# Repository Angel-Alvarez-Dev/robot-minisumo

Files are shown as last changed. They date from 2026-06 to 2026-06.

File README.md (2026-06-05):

# Robot Minisumo

Robot Minisumo autonomo basado en Arduino Nano y Arduino Nano Expansion I/O Shield. El prototipo fisico fue probado y se encuentra funcional con sensores TCRT5000, HC-SR04, buzzer KY-012 y servomotores SG90.

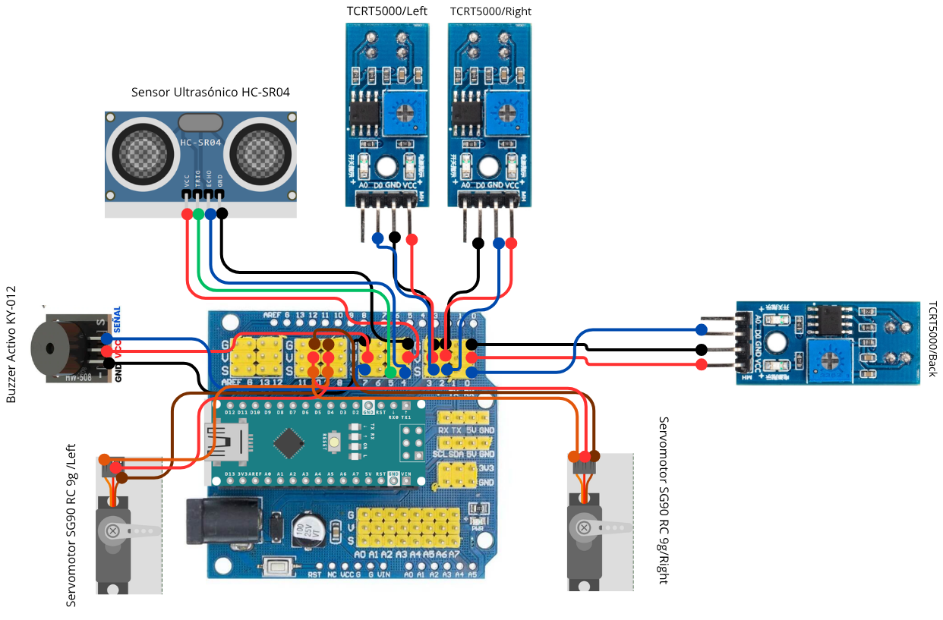
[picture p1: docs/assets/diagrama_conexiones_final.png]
Diagrama final de conexiones


PDF del diagrama final: [docs/assets/diagrama_conexiones_final.pdf](docs/assets/diagrama_conexiones_final.pdf)

## Estado del proyecto

El prototipo fisico del Robot Minisumo fue probado y se encuentra funcional. El Arduino Nano tiene cargada y confirmada por Serial la version funcional `1.0.0-funcional` del firmware final. El repositorio contiene firmware, documentacion, esquematicos KiCad, validacion logica y reporte academico en carpeta separada.

## Componentes

| Componente | Cantidad | Funcion |
| --- | --- | --- |
| Porta Pilas AA Con Plug Para 4/6 Pilas | 1 (EL DE 4) | Fuente portatil para alimentar el robot mediante la Shield. |
| Paquete De 4 Pilas Alcalinas AA | 1.0 | Energia para el porta pilas AA. |
| Sensor Seguidor de Linea TCRT5000 Optico Infrarrojo 3.3 V a 5 V | 3.0 | Deteccion de borde de dohyo con tres sensores Left, Right y Back. |
| Sensor Ultrasónico HC-SR04 | 2.0 | Componente de soporte del robot. |
| Buzzer Activo KY-012 | 2.0 | Indicador sonoro de arranque, ataque y evasion. |
| Arduino Nano V3 + cable USB | 1.0 | Control principal de lectura de sensores y actuadores. |
| Shield para Arduino Nano Expansion I/O | 1.0 | Control principal de lectura de sensores y actuadores. |
| Servomotor SG90 RC 9g | 2.0 | Traccion diferencial del robot con SG90 confirmados funcionales. |
| Llantas de plástico | 2.0 | Contacto mecanico de traccion para los servos. |
| Cables Dupont Largos 20cm HH MH MM | 1-HH/1MH/1MM (uNO DE CADA UNO) | Cableado de senales, VCC y GND entre modulos y Shield. |

## Pinout final

| Componente | Pin del componente | Pin Arduino/Shield | Senal |
| --- | --- | --- | --- |
| TCRT5000 Left | DO | D3 | TCRT_LEFT |
| TCRT5000 Right | DO | D2 | TCRT_RIGHT |
| TCRT5000 Back | DO | D0 | TCRT_BACK |
| HC-SR04 | Trig | D4 | TRIG_HCSR04 |
| HC-SR04 | Echo | D5 | ECHO_HCSR04 |
| KY-012 | S | D7 | BUZZER_SIG |
| SG90 Left | Signal | D9 | SERVO_LEFT |
| SG90 Right | Signal | D10 | SERVO_RIGHT |

## Advertencias tecnicas

- D0 corresponde a RX Serial del Arduino Nano. En el prototipo final se usa para `TCRT_BACK`; si interfiere con la carga de firmware o monitor serial, desconectar temporalmente el DO del sensor trasero.
- Todos los modulos deben compartir GND comun.
- La Shield de expansion organiza conexiones, pero no aumenta la capacidad de corriente del Arduino Nano.
- Si los servos reinician el Arduino o vibran, usar alimentacion externa estable de 5 V para servos con GND comun.

## Compilar firmware

```powershell
$Cli = 'A:\robot-minisumo\tools\arduino-cli\arduino-cli.exe'
$Config = 'A:\robot-minisumo\.arduino-cli\arduino-cli.yaml'
& $Cli --config-file $Config compile --fqbn arduino:avr:nano firmware\robot_minisumo_final
```

## Firmware cargado

Firmware final: `firmware/robot_minisumo_final/robot_minisumo_final.ino`.

Version confirmada desde Serial Monitor:

```text
Robot Minisumo Final
1.0.0-funcional
FUNCIONAL_PROBADO
```

La carga fue confirmada en `COM8` usando `arduino:avr:nano`.

## KiCad

Abrir `hardware/kicad/robot_minisumo.kicad_pro`. El esquematico representa el montaje sobre Arduino Nano Expansion I/O Shield; no se disena PCB personalizada.

## Documentacion

- BOM final: `docs/bom_final.md`.
- Conexiones finales: `docs/lista_conexiones_final.md`.
- Panel de monitoreo: `docs/panel_web_monitoreo.md`.
- Algoritmos y pseudocodigo: `docs/algoritmos.md`, `docs/pseudocodigo.md`.
- Validacion: `validation/` y `simulation/`.
- Reporte academico: `report/`.

## Panel web de monitoreo

Abrir `web-control/index.html` o servir el repositorio en `http://localhost:8080/web-control/`.

El panel esta disenado para grabar y explicar el robot en funcionamiento en una sola pantalla de laptop. Muestra conexion, firmware, distancia, accion actual, modo real/demo, procesos activos, TCRT5000 Left/Right/Back, HC-SR04, servos SG90, buzzer KY-012, movimiento y eventos recientes.

Incluye:

- Modo demo / grabacion con estados simulados desde el panel.
- Pruebas rapidas: sensores, servos, buzzer, ultrasonico, demo borde, demo ataque, demo buscar y stop.
- Conexion opcional por Web Serial API a 9600 baudios.
- Envio de comandos `CMD:TEST_SENSORES`, `CMD:TEST_SERVOS`, `CMD:TEST_BUZZER`, `CMD:TEST_ULTRASONICO`, `CMD:DEMO_BORDE`, `CMD:DEMO_ATAQUE`, `CMD:DEMO_BUSCAR` y `CMD:STOP`.
- Parseo de mensajes `STATE`, `TCRT_LEFT`, `TCRT_RIGHT`, `TCRT_BACK`, `DIST_CM`, `OPONENTE`, `MOTOR_LEFT`, `MOTOR_RIGHT` y `BUZZER`.
- Compatibilidad con la linea de prueba `Distancia=<cm> L=<0/1> R=<0/1> B=<0/1>`.

## Evidencia del proyecto

La evidencia multimedia final esta organizada en `assets/` y documentada en `docs/evidencia_multimedia.md` e `docs/inventario_multimedia.md`.

| Carpeta | Contenido |
| --- | --- |
| `assets/images/conexiones/` | Diagrama final de conexiones del robot. |
| `assets/images/montaje/` | Fotografias del prototipo fisico ensamblado. |
| `assets/images/pruebas/` | Evidencia visual de alimentacion y sensores activos. |
| `assets/images/panel/` | Capturas del panel web de monitoreo. |
| `assets/videos/pruebas/` | Videos cortos de pruebas por componente o comportamiento. |
| `assets/videos/demo_final/` | Video principal de funcionamiento final. |

Archivo principal para demostracion: `assets/videos/demo_final/robot_minisumo_demo_funcionamiento_final_01.mp4`.

La publicacion en GitHub fue revisada en `docs/github_publicacion.md`; los videos integrados son ligeros y no requieren Git LFS.
## Licencia

Proyecto academico y tecnico. Agregar licencia explicita si se publicara para reutilizacion externa.

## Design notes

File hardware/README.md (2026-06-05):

# Hardware

El hardware final usa Arduino Nano sobre Arduino Nano Expansion I/O Shield. El montaje se documenta por bloques y no requiere PCB personalizada.

| Archivo | Proposito |
| --- | --- |
| `conexiones_robot_minisumo.md` | Conexion detallada por bloque |
| `esquematicos.md` | Descripcion del esquematico |
| `kicad/robot_minisumo.kicad_sch` | Proyecto KiCad documental |
| `assets/diagrama_conexiones.png` | Diagrama visual |

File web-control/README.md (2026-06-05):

# Panel compacto Robot Minisumo

Panel web local para grabar el video final del Robot Minisumo sin scroll innecesario. La vista concentra proceso activo, sensores, actuadores, movimiento, pruebas rapidas y eventos recientes.

## Abrir

```powershell
cd A:\robot-minisumo
python -m http.server 8080
```

Abrir:

```text
http://localhost:8080/web-control/
```

Tambien puede abrirse directo con `web-control/index.html`, pero `localhost` es mejor para Web Serial.

## Vista en tiempo real

- Conexion: conectado, desconectado o modo demo.
- Firmware: detectado o no detectado.
- Distancia: valor HC-SR04 en cm o sin eco.
- Accion: buscar, atacar, evadir borde, giro, retroceso o detenido.
- Modo: real o demo.
- TCRT Left, Right y Back: libre, borde o inestable.
- Servo Left y Servo Right: stop, avanza, atras, gira o ataque.
- Buzzer: ON/OFF.
- Movimiento resumido del robot.

## Pruebas rapidas

| Boton | Comando Serial | Efecto visual |
| --- | --- | --- |
| Test sensores | `CMD:TEST_SENSORES` | Lectura linea y tarjetas TCRT |
| Test servos | `CMD:TEST_SERVOS` | Movimiento de servos |
| Test buzzer | `CMD:TEST_BUZZER` | Buzzer ON temporal |
| Test ultrasonico | `CMD:TEST_ULTRASONICO` | Distancia y oponente |
| Demo borde | `CMD:DEMO_BORDE` | Borde, retroceso y buzzer |
| Demo ataque | `CMD:DEMO_ATAQUE` | Ataque y oponente cerca |
| Demo buscar | `CMD:DEMO_BUSCAR` | Busqueda/giro |
| Stop | `CMD:STOP` | Detiene motores |

Si Arduino esta conectado por Web Serial, el panel envia el comando. Si no esta conectado, el panel activa modo demo y simula el estado para grabacion.

## Web Serial

El boton `Conectar Arduino` abre Web Serial API a 9600 baudios. El firmware final reconoce los comandos `CMD:*` anteriores y publica telemetria.

Mensajes leidos por el panel:

- `STATE:BUSCAR`
- `STATE:ATACAR`
- `STATE:EVITAR_BORDE`
- `STATE:RETROCESO` o `STATE:RETROCEDER`
- `STATE:GIRO_IZQUIERDO`
- `STATE:GIRO_DERECHO`
- `STATE:DETENIDO` o `STATE:DETENER`
- `TCRT_LEFT:0`
- `TCRT_RIGHT:1`
- `TCRT_BACK:0`
- `DIST_CM:23`
- `OPONENTE:1`
- `MOTOR_LEFT:AVANZAR`
- `MOTOR_RIGHT:RETROCEDER`
- `BUZZER:ON`
- `BUZZER:OFF`

Los mensajes desconocidos no rompen la interfaz; solo aparecen en eventos recientes.

## Limitaciones

- Web Serial requiere navegador compatible, normalmente Chromium.
- Para ver telemetria real hay que cargar el firmware actualizado en Arduino.
- D0/RX se usa para `TCRT_BACK`; desconectar temporalmente ese sensor si interfiere con carga de firmware.

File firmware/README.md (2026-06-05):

# Firmware

## Version funcional cargada

El Arduino Nano tiene cargada y confirmada por Serial la version funcional del firmware final:

```text
Robot Minisumo Final
1.0.0-funcional
FUNCIONAL_PROBADO
```

Archivo final: `firmware/robot_minisumo_final/robot_minisumo_final.ino`.

Puerto confirmado: `COM8`.

FQBN usado para carga: `arduino:avr:nano`.

## Pinout final

| Senal | Pin |
| --- | --- |
| TCRT_LEFT | D3 |
| TCRT_RIGHT | D2 |
| TCRT_BACK | D0 |
| TRIG_HCSR04 | D4 |
| ECHO_HCSR04 | D5 |
| BUZZER_SIG | D7 |
| SERVO_LEFT | D9 |
| SERVO_RIGHT | D10 |

D0 se usa para `TCRT_BACK` segun el pinout real probado. D0 corresponde a RX Serial; si falla la carga o el monitor serial, desconectar temporalmente el cable DO del TCRT Back.

## Calibracion final

- `LINE_ACTIVE_LOW = true`.
- Distancia de ataque: 35 cm.
- SG90 Left en D9: 1700 us avanza y 1300 us retrocede.
- SG90 Right en D10: 1300 us acompana el avance y 1700 us retrocede por montaje invertido.
- Detencion: 1500 us.

## Sketches

- `test_hcsr04`: prueba Trig D4 / Echo D5.
- `test_tcrt5000`: prueba RAW Left D3, Right D2, Back D0.
- `test_servos`: prueba D9/D10 con pulsos manuales.
- `test_buzzer`: prueba KY-012 en D7.
- `test_servo_d9`: prueba aislada de calibracion D9.
- `robot_minisumo_final`: firmware autonomo final.

## Comandos Serial del firmware final

- `s`: imprimir sensores en formato `Distancia=<cm> L=<0/1> R=<0/1> B=<0/1>`.
- `v`: prueba breve de servos.
- `b`: sonar buzzer.
- `a`: avanzar 500 ms.
- `d`: detener.

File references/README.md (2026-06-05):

# Referencias tecnicas

Carpeta minima de referencias de componentes.

Se conservan solo archivos necesarios para documentar y validar el proyecto:

- Datasheets relevantes.
- Pinouts.
- Imagenes de dimensiones.
- Esquematico de la shield.

No se conservan en la estructura limpia los paquetes CAD completos, renders duplicados ni archivos temporales de modelado.

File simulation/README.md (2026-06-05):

# Simulacion

La validacion es logica y documental hasta realizar pruebas fisicas. El esquematico KiCad representa bloques de conexion sobre la Shield.

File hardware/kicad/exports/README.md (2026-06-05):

# Exportaciones KiCad

Pendiente ejecutar con KiCad instalado:

```powershell
kicad-cli sch erc hardware\kicad\robot_minisumo.kicad_sch --output hardware\kicad\exports\erc_report.txt
kicad-cli sch export pdf hardware\kicad\robot_minisumo.kicad_sch --output hardware\kicad\exports\robot_minisumo_schematic.pdf
kicad-cli sch export svg hardware\kicad\robot_minisumo.kicad_sch --output hardware\kicad\exports\
```

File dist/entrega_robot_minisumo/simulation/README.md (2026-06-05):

# Simulacion Y Validacion

Estado del prototipo fisico: **funcional**.

La validacion combina pruebas fisicas por modulo, compilacion de firmware y analisis de logica. El proyecto no depende de una simulacion electrica analogica compleja; el comportamiento se valida por casos de entrada/salida y esquematico KiCad documental.

| Caso | Entrada | Accion esperada | Resultado esperado | Estado |
| --- | --- | --- | --- | --- |
| HC-SR04 detecta oponente | Distancia 5 a 35 cm | Atacar | Servos avanzan y buzzer breve | Validado logicamente |
| HC-SR04 no detecta oponente | Distancia > 35 cm o sin eco | Buscar | Robot gira buscando | Validado logicamente |
| TCRT5000 Left detecta borde | Left activo | Evadir | Retrocede y gira derecha | Validado logicamente |
| TCRT5000 Right detecta borde | Right activo | Evadir | Retrocede y gira izquierda | Validado logicamente |
| TCRT5000 Back detecta borde | Back activo en D0 | Evadir | Retrocede y giro extendido | Validado logicamente |
| Servo izquierdo responde | Pulso D9 | Mover | 1700 us avanza; 1300 us retrocede | Aprobado fisico |
| Servo derecho responde | Pulso D10 | Mover | Acompana invertido por montaje | Aprobado fisico |
| Buzzer responde | D7 alto | Sonar | Sonido confirmado | Aprobado fisico |
| Robot busca | Sin borde y sin oponente | Girar | Busqueda continua | Validado |
| Robot ataca | Oponente cercano | Avanzar | Ataque con servos | Validado |
| Robot evita borde | TCRT activo | Retroceder/girar | No sale del area | Validado |
| Robot funciona fisicamente | Pinout final conectado | Operar | Prototipo funcional | Aprobado fisico |

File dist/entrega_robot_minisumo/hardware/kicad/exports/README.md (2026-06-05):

# Exportaciones KiCad

Ejecutar si `kicad-cli` esta disponible:

```powershell
kicad-cli version
kicad-cli sch erc hardware/kicad/robot_minisumo.kicad_sch --output hardware/kicad/exports/erc_report.txt
kicad-cli sch export pdf hardware/kicad/robot_minisumo.kicad_sch --output hardware/kicad/exports/robot_minisumo_schematic.pdf
kicad-cli sch export svg hardware/kicad/robot_minisumo.kicad_sch --output hardware/kicad/exports/
```

Si `kicad-cli` no esta instalado, abrir `hardware/kicad/robot_minisumo.kicad_pro` en KiCad y ejecutar manualmente Inspeccion electrica y Exportar PDF/SVG.

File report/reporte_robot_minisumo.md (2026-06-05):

# Reporte Academico: Robot Minisumo

## 1. Portada

**Alumno:** Álvarez Villegas José Ángel  
**Materia:** MICROCONTROLADORES  
**Grupo:** 2809  
**Proyecto:** Robot Minisumo  
**Fecha:** 2026-06-05

## 2. Indice

1. Introduccion.
2. Objetivo general.
3. Objetivos especificos.
4. Investigacion documental.
5. Materiales y equipo.
6. Lista final de conexiones.
7. Diagrama final de conexiones.
8. Esquematicos del circuito.
9. Funcionamiento del sistema.
10. Codigo implementado.
11. Panel de monitoreo para demostracion.
12. Algoritmos.
13. Pseudocodigo.
14. Diagramas de flujo.
15. Simulacion y validacion.
16. Pruebas realizadas.
17. Evidencia del prototipo funcional.
18. Resultados.
19. Conclusiones.
20. Referencias.
21. Anexos.

## 3. Introduccion

El Robot Minisumo es un sistema autonomo basado en Arduino Nano que usa sensores de linea para detectar el borde del area de competencia, un sensor ultrasonico HC-SR04 para localizar al oponente, servomotores SG90 para traccion diferencial y un buzzer KY-012 para senalizacion.

## 4. Objetivo general

Consolidar un prototipo funcional de Robot Minisumo con firmware, documentacion, esquematico KiCad, validacion y carpeta de entrega coherentes con las conexiones finales reales.

## 5. Objetivos especificos

- Documentar la BOM final.
- Documentar la lista final de conexiones.
- Implementar firmware modular para busqueda, ataque y evasion de borde.
- Validar sensores, servos y buzzer con pruebas individuales.
- Generar reporte academico y entregables finales.

## 6. Investigacion documental

El Arduino Nano se usa como controlador principal por su compatibilidad con el ecosistema Arduino y disponibilidad de entradas/salidas digitales. El HC-SR04 mide distancia por tiempo de vuelo ultrasonico. Los TCRT5000 integran emisor infrarrojo y fototransistor para detectar cambios de reflectancia. Los SG90 de rotacion continua permiten traccion simple mediante pulsos tipo servo, y el KY-012 entrega senal sonora con control digital.

## 7. Materiales y equipo

Ver `docs/bom_final.md` y `report/assets/bom_final.md`.

## 8. Lista final de conexiones

| Componente | Pin del componente | Pin Arduino/Shield | Senal |
| --- | --- | --- | --- |
| TCRT5000 Left | DO | D3 | TCRT_LEFT |
| TCRT5000 Right | DO | D2 | TCRT_RIGHT |
| TCRT5000 Back | DO | D0 | TCRT_BACK |
| HC-SR04 | Trig | D4 | TRIG_HCSR04 |
| HC-SR04 | Echo | D5 | ECHO_HCSR04 |
| KY-012 | S | D7 | BUZZER_SIG |
| SG90 Left | Signal | D9 | SERVO_LEFT |
| SG90 Right | Signal | D10 | SERVO_RIGHT |

Advertencia: D0 y D1 corresponden a RX/TX del Arduino Nano. El prototipo final usa D0 para `TCRT_BACK`, por lo que se debe desconectar temporalmente durante carga si interfiere.

## 9. Diagrama final de conexiones

Diagrama final de conexiones

Version PDF del diagrama final: `assets/diagrama_conexiones_final.pdf`.

## 10. Esquematicos del circuito

El proyecto KiCad esta en `hardware/kicad/robot_minisumo.kicad_pro`. El esquematico es documental y representa el montaje real sobre Shield, con GND comun, VCC_5V para sensores/buzzer y alimentacion estable para servos.

## 11. Funcionamiento del sistema

El robot da prioridad a la deteccion de borde. Si cualquier TCRT5000 detecta borde, retrocede y gira. Si no hay borde, mide distancia con HC-SR04. Si detecta un oponente a 35 cm o menos, avanza para atacar. Si no detecta oponente, busca girando.

## 12. Codigo implementado

```cpp
const byte PIN_TCRT_LEFT = 3;
const byte PIN_TCRT_RIGHT = 2;
const byte PIN_TCRT_BACK = 0;
const byte PIN_TRIG_HCSR04 = 4;
const byte PIN_ECHO_HCSR04 = 5;
const byte PIN_BUZZER = 7;
const byte PIN_SERVO_LEFT = 9;
const byte PIN_SERVO_RIGHT = 10;
```

Funciones principales: `configurarPines`, `leerUltrasonico`, `leerSensoresLinea`, `avanzar`, `retroceder`, `girarIzquierda`, `girarDerecha`, `detenerRobot`, `buscarOponente`, `atacar`, `evitarBorde`, `sonarBuzzer`, `pruebaSensores`, `pruebaUltrasonico`, `pruebaServos`, `procesarComandoPanel` y `publicarEstadoPanel`.

## 13. Panel de monitoreo para demostracion

Se agrego un panel web de monitoreo compacto en `web-control/` para apoyar la grabacion del robot funcionando. El objetivo del panel es mostrar en una sola pantalla de laptop lo importante de la operacion: proceso activo, sensores, actuadores, movimiento, pruebas rapidas y eventos recientes.

Componentes monitoreados:

- HC-SR04 ultrasonico.
- TCRT5000 Left, Right y Back.
- Servo/Motor izquierdo SG90.
- Servo/Motor derecho SG90.
- Buzzer KY-012.
- Movimiento resumido del robot.

Procesos mostrados:

- Inicializacion.
- Lectura de linea.
- Lectura ultrasonica.
- Buscar.
- Ataque.
- Evadir borde.
- Retroceso.
- Giro izquierdo.
- Giro derecho.
- Detenido.

El panel incluye modo demo / grabacion. En este modo los estados son simulados desde el panel y se indica claramente al usuario que no corresponden a lecturas reales del Arduino. Esto permite preparar tomas de video donde se expliquen casos como borde, ataque, busqueda, pruebas de sensores, pruebas de servos, buzzer y detencion.

Tambien se implemento integracion opcional con Web Serial API. Si el navegador soporta Web Serial, el boton `Conectar Arduino` permite seleccionar el puerto del Arduino a 9600 baudios. El firmware final publica mensajes como `STATE:BUSCAR`, `STATE:ATACAR`, `TCRT_LEFT:1`, `DIST_CM:20`, `MOTOR_LEFT:AVANZAR` y `BUZZER:ON`. El panel parsea esos mensajes y actualiza sensores, actuadores, procesos y registro compacto de eventos.

El panel tambien incluye botones de pruebas rapidas. Si existe conexion Web Serial, envia comandos como `CMD:TEST_SENSORES`, `CMD:TEST_SERVOS`, `CMD:TEST_BUZZER`, `CMD:TEST_ULTRASONICO`, `CMD:DEMO_BORDE`, `CMD:DEMO_ATAQUE`, `CMD:DEMO_BUSCAR` y `CMD:STOP`. Si no existe conexion, los botones activan modo demo y actualizan visualmente el tablero.

Descripcion visual del panel: en la parte superior se muestran conexion, firmware, distancia, accion y modo. La zona central contiene chips de procesos y tarjetas compactas para TCRT Left/Right/Back, HC-SR04, Servo Left, Servo Right, Buzzer y movimiento. Debajo se ubican los botones de pruebas rapidas y un log limitado a eventos recientes.

La utilidad principal durante la grabacion es que toda la informacion importante cabe en la vista de la laptop, sin depender de scroll, y permite explicar que sensor se activo, que actuador responde y que movimiento hace el robot.

## 14. Algoritmos

Ver `docs/algoritmos.md`.

## 15. Pseudocodigo

Ver `docs/pseudocodigo.md`.

## 16. Diagramas de flujo

Ver `docs/diagramas_flujo.md`.

## 17. Simulacion y validacion

Ver `simulation/casos_prueba.md`, `simulation/validacion_logica.md` y `validation/registro_pruebas.md`.

## 18. Pruebas realizadas

| Prueba | Resultado esperado | Resultado observado | Estado |
| --- | --- | --- | --- |
| Buzzer KY-012 | Sonido intermitente al ejecutar test_buzzer | Sonido confirmado por usuario | Aprobado |
| HC-SR04 | Lecturas de distancia en cm | Lecturas observadas: 151, 152, 46, 47, 4, 11, 16, 7 y 6 cm | Aprobado |
| TCRT5000 Left | Cambio digital al detectar linea/borde | Los tres sensores funcionan con tabla final: Left D3, Right D2, Back D0 | Aprobado |
| TCRT5000 Right | Cambio digital al detectar linea/borde | Los tres sensores funcionan con tabla final: Left D3, Right D2, Back D0 | Aprobado |
| TCRT5000 Back | Cambio digital al detectar linea/borde | Funciona en D0; advertencia por RX Serial documentada | Aprobado |
| Servo D9 aislado | Movimiento adelante y atras | 1700 us adelanta y 1300 us atrasa | Aprobado |
| Servos D9/D10 conjunto | D9 avanza y D10 acompana sin quedarse quieto | D9 avanza, D10 acompana invertido por montaje, ninguno se queda quieto | Aprobado |
| Firmware final | Arranque serial y logica cargada | Firmware final cargado en COM8 y arranque serial observado | Aprobado |
| Panel web compacto | Mostrar estado general, procesos, componentes, pruebas y eventos en una pantalla | Panel compacto actualizado con modo demo, pruebas rapidas y Web Serial opcional | Aprobado |
| Robot fisico | Prototipo opera con sensores y actuadores finales | Estado reportado por usuario: robot fisico funcional | Aprobado |

## 19. Evidencia del prototipo funcional

La evidencia multimedia del prototipo funcional se integro en `assets/` y se documento en `docs/evidencia_multimedia.md`, `docs/inventario_multimedia.md` y `validation/evidencia_funcionamiento.md`.

Evidencia visual incluida:

| Evidencia | Archivo | Utilidad |
| --- | --- | --- |
| Diagrama final de conexiones | `assets/robot_minisumo_conexiones_diagrama_final_01.png` | Explica el pinout real usado en el robot. |
| Fotografia frontal | `assets/robot_minisumo_montaje_frontal_hcsr04_01.jpg` | Muestra el HC-SR04 al frente del robot. |
| Fotografia posterior/electronica | `assets/robot_minisumo_montaje_posterior_electronica_01.jpg` | Muestra Arduino Nano, shield, buzzer y cableado. |
| Fotografia de pruebas | `assets/robot_minisumo_pruebas_alimentacion_sensores_01.jpg` | Muestra alimentacion y sensores activos. |
| Captura del panel web | `assets/robot_minisumo_panel_monitoreo_desktop_01.png` | Muestra el panel minimalista usado durante la grabacion. |

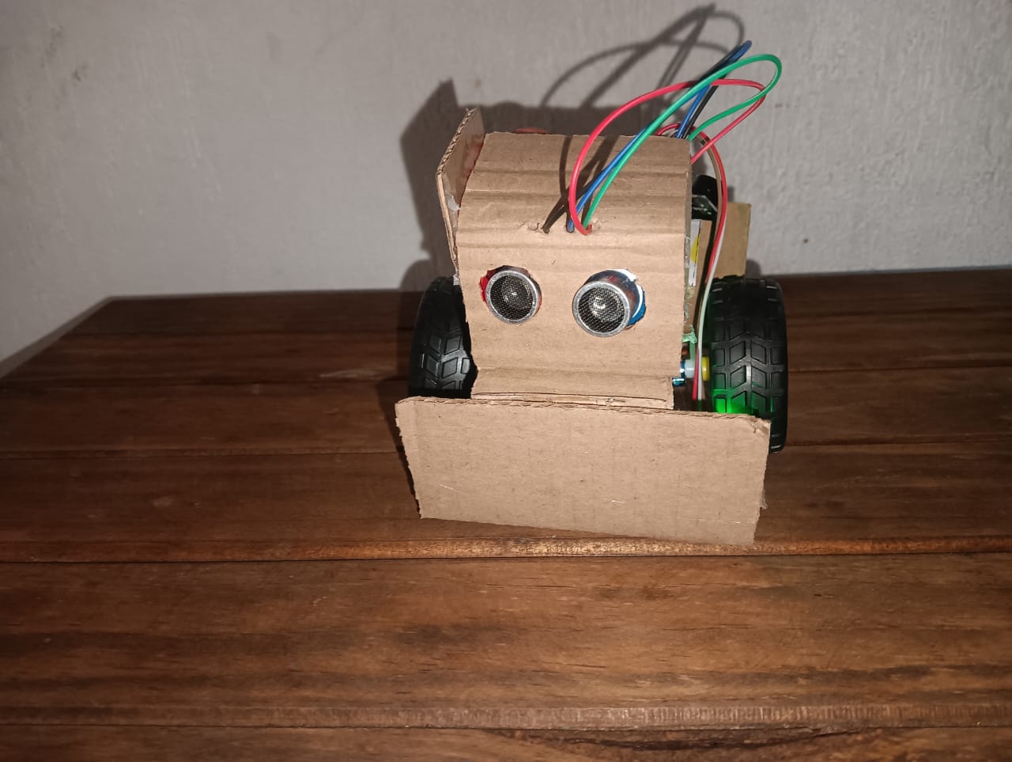
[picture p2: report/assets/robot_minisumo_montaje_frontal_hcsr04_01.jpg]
Montaje frontal del prototipo


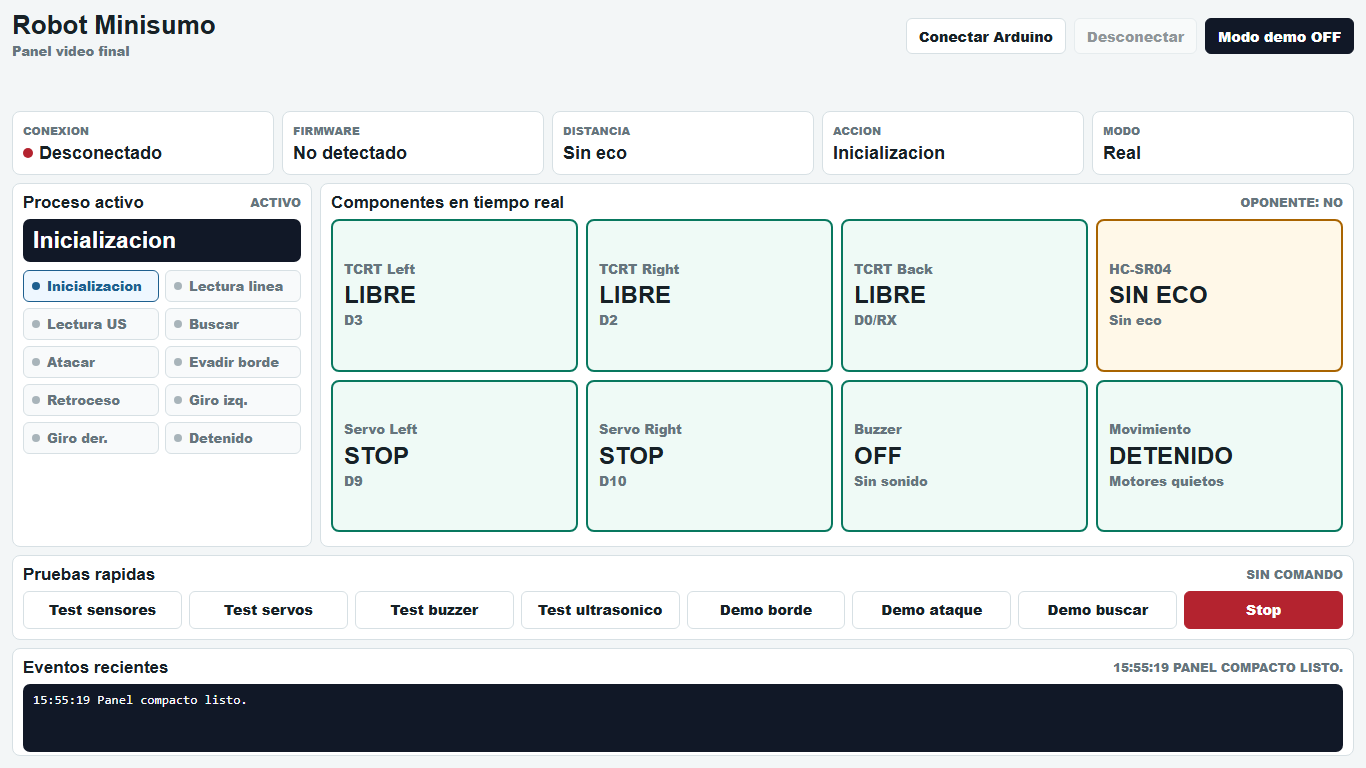
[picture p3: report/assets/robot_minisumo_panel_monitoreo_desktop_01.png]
Panel web de monitoreo


Evidencia en video incluida:

| Video | Duracion | Uso |
| --- | --- | --- |
| `assets/videos/pruebas/robot_minisumo_pruebas_buzzer_arranque_01.mp4` | 00:00:02 | Buzzer / arranque. |
| `assets/videos/pruebas/robot_minisumo_pruebas_movimiento_servos_01.mp4` | 00:00:09 | Movimiento de servos. |
| `assets/videos/pruebas/robot_minisumo_pruebas_sensores_linea_01.mp4` | 00:00:06 | Sensores TCRT5000. |
| `assets/videos/pruebas/robot_minisumo_pruebas_ultrasonico_busqueda_01.mp4` | 00:00:09 | Busqueda / HC-SR04. |
| `assets/videos/demo_final/robot_minisumo_demo_funcionamiento_final_01.mp4` | 00:00:15 | Demostracion final del robot funcional. |

Esta evidencia permite explicar durante el video final que componentes estan montados, que pruebas se realizaron y como el panel acompana la demostracion en tiempo real.

## 20. Resultados

El prototipo fisico quedo funcional. Se confirmaron buzzer, HC-SR04, tres TCRT5000 y servos SG90. El pinout final real quedo documentado y el firmware final se cargo en COM8.

La version funcional cargada fue confirmada por Serial Monitor:

```text
Robot Minisumo Final
1.0.0-funcional
FUNCIONAL_PROBADO
```

## 21. Conclusiones

El proyecto final integra hardware, firmware y documentacion de forma coherente con el robot funcional real. La principal restriccion tecnica es el uso de D0 para el sensor trasero, debido a que comparte RX Serial. La recomendacion es desconectar temporalmente ese sensor durante cargas de firmware o futuras depuraciones seriales.

## 22. Referencias

- Documentacion Arduino Nano.
- Hojas tecnicas HC-SR04, TCRT5000, SG90 y KY-012.
- Documentacion KiCad.
- BOM y lista final de conexiones anexadas al proyecto.

## 23. Anexos

- `firmware/`.
- `hardware/kicad/`.
- `docs/`.
- `simulation/`.
- `validation/`.
- `web-control/`.

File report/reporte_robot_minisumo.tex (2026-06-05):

\documentclass[12pt,letterpaper]{article}
\usepackage[utf8]{inputenc}
\usepackage[T1]{fontenc}
\usepackage[spanish]{babel}
\usepackage{geometry}
\usepackage{graphicx}
\usepackage{longtable}
\usepackage{hyperref}
\geometry{margin=2.2cm}
\title{Robot Minisumo}
\author{Álvarez Villegas José Ángel\\MICROCONTROLADORES\\Grupo 2809}
\date{2026-06-05}
\begin{document}
\maketitle
\tableofcontents
\newpage
\section{Introducción}
El Robot Minisumo es un prototipo autónomo basado en Arduino Nano, sensores TCRT5000, HC-SR04, buzzer KY-012 y servomotores SG90.
\section{Objetivo general}
Consolidar un prototipo funcional con documentación, firmware, validación, esquemático KiCad y entregables finales.
\section{Materiales y equipo}
La BOM final se documenta en \texttt{docs/bom\_final.md} y \texttt{report/assets/bom\_final.md}.
\section{Lista final de conexiones}
\begin{longtable}{p{4cm}p{3cm}p{3cm}p{4cm}}
\textbf{Componente} & \textbf{Pin componente} & \textbf{Pin Arduino} & \textbf{Señal}\\
TCRT5000 Left & DO & D3 & TCRT\_LEFT \\
TCRT5000 Right & DO & D2 & TCRT\_RIGHT \\
TCRT5000 Back & DO & D0 & TCRT\_BACK \\
HC-SR04 & Trig & D4 & TRIG\_HCSR04 \\
HC-SR04 & Echo & D5 & ECHO\_HCSR04 \\
KY-012 & S & D7 & BUZZER\_SIG \\
SG90 Left & Signal & D9 & SERVO\_LEFT \\
SG90 Right & Signal & D10 & SERVO\_RIGHT \\
\end{longtable}
\textbf{Advertencia:} D0 y D1 corresponden a RX/TX del Arduino Nano. El prototipo final usa D0 para TCRT Back, por lo que puede ser necesario desconectarlo durante carga de firmware.
\section{Diagrama final de conexiones}

Version PDF del diagrama final: \texttt{assets/diagrama\_conexiones\_final.pdf}.
\section{Funcionamiento}
El robot prioriza la evasión de borde; si no hay borde, mide distancia y ataca cuando el oponente está a 35 cm o menos. Si no detecta oponente, busca girando.
\section{Código implementado}
El firmware final se encuentra en \texttt{firmware/robot\_minisumo\_final/robot\_minisumo\_final.ino} e incluye funciones modulares de lectura, movimiento, ataque, búsqueda, evasión y pruebas.
\section{Pseudocódigo y diagramas}
Ver \texttt{docs/pseudocodigo.md} y \texttt{docs/diagramas\_flujo.md}.
\section{Simulación y validación}
La validación se documenta por casos en \texttt{simulation/casos\_prueba.md}.
\section{Pruebas realizadas}
\begin{longtable}{p{9cm}p{5cm}}
\textbf{Prueba} & \textbf{Estado}\\
Buzzer KY-012 & Aprobado \\
HC-SR04 & Aprobado \\
TCRT5000 Left & Aprobado \\
TCRT5000 Right & Aprobado \\
TCRT5000 Back & Aprobado \\
Servo D9 aislado & Aprobado \\
Servos D9/D10 conjunto & Aprobado \\
Firmware final & Aprobado \\
Robot fisico & Aprobado \\
\end{longtable}
\section{Evidencia del prototipo funcional}
La evidencia multimedia del prototipo funcional se organizo en \texttt{assets/} y se documento en \texttt{docs/evidencia\_multimedia.md}, \texttt{docs/inventario\_multimedia.md} y \texttt{validation/evidencia\_funcionamiento.md}.

\begin{longtable}{p{5cm}p{5cm}p{4cm}}
\textbf{Evidencia} & \textbf{Archivo} & \textbf{Utilidad}\\
Diagrama final & \texttt{assets/images/conexiones/robot\_minisumo\_conexiones\_diagrama\_final\_01.png} & Pinout real del robot. \\
Montaje frontal & \texttt{assets/robot\_minisumo\_montaje\_frontal\_hcsr04\_01.jpg} & HC-SR04 al frente del prototipo. \\
Montaje posterior & \texttt{assets/robot\_minisumo\_montaje\_posterior\_electronica\_01.jpg} & Arduino Nano, shield, buzzer y cableado. \\
Panel web & \texttt{assets/robot\_minisumo\_panel\_monitoreo\_desktop\_01.png} & Panel minimalista usado durante la grabacion. \\
Video final & \texttt{assets/videos/demo\_final/robot\_minisumo\_demo\_funcionamiento\_final\_01.mp4} & Demostracion del robot funcionando. \\
\end{longtable}





Los videos incluidos son ligeros para publicacion en GitHub; el archivo mas grande pesa 3.39 MB, por lo que no se uso Git LFS.

\\section{Resultados}
El prototipo físico se encuentra funcional. Se confirmaron sensores, buzzer y servos SG90 con el pinout final real.
\section{Conclusiones}
El proyecto queda listo para entrega académica y publicación técnica. El principal cuidado operativo es el uso de D0/RX para TCRT Back.
\section{Referencias}
Arduino Nano, HC-SR04, TCRT5000, SG90, KY-012, KiCad y documentación generada del proyecto.
\end{document}

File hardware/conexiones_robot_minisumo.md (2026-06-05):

# Lista Final De Conexiones

Fuente valida: `Conexiones_Robot_Minisumo.xlsx` anexo e imagen final `diagrama_conexiones_final.png`.

Version PDF del diagrama: `hardware/assets/diagrama_conexiones_final.pdf`.

Pinout final probado:

- TCRT5000 Left: D3.
- TCRT5000 Right: D2.
- TCRT5000 Back: D0.
- HC-SR04: Trig D4, Echo D5.
- Buzzer KY-012: D7.
- SG90 Left: D9.
- SG90 Right: D10.

> Advertencia: D0 y D1 corresponden a RX/TX del Arduino Nano. D0 se usa por `TCRT_BACK` en el prototipo real y puede interferir con la carga de firmware o el Serial Monitor. Si ocurre, desconectar temporalmente el cable DO del TCRT Back durante la carga.

| Componente | Pin del componente | Pin Arduino/Shield | Senal | Tipo | Observaciones |
| --- | --- | --- | --- | --- | --- |
| TCRT5000 Left | VCC | VCC | VCC_5V | Alimentacion | Modulo de linea izquierdo. |
| TCRT5000 Left | GND | GND | GND | Alimentacion | GND comun. |
| TCRT5000 Left | DO | D3 | TCRT_LEFT | Digital entrada | Pinout final real probado. |
| TCRT5000 Right | VCC | VCC | VCC_5V | Alimentacion | Modulo de linea derecho. |
| TCRT5000 Right | GND | GND | GND | Alimentacion | GND comun. |
| TCRT5000 Right | DO | D2 | TCRT_RIGHT | Digital entrada | Pinout final real probado. |
| TCRT5000 Back | VCC | VCC | VCC_5V | Alimentacion | Modulo de linea trasero. |
| TCRT5000 Back | GND | GND | GND | Alimentacion | GND comun. |
| TCRT5000 Back | DO | D0 | TCRT_BACK | Digital entrada | D0 es RX Serial; desconectar durante carga si interfiere. |
| HC-SR04 | VCC | VCC | VCC_5V | Alimentacion | Sensor frontal de distancia. |
| HC-SR04 | GND | GND | GND | Alimentacion | GND comun. |
| HC-SR04 | Trig | D4 | TRIG_HCSR04 | Digital salida | Pulso de disparo ultrasonico. |
| HC-SR04 | Echo | D5 | ECHO_HCSR04 | Digital entrada | Medicion con pulseIn. |
| Buzzer KY-012 | VCC | VCC | VCC_5V | Alimentacion | Indicador sonoro activo. |
| Buzzer KY-012 | GND | GND | GND | Alimentacion | GND comun. |
| Buzzer KY-012 | S | D7 | BUZZER_SIG | Digital salida | Prueba fisica aprobada. |
| SG90 Left | VCC | VCC | VCC_SERVO/5V | Alimentacion | Verificar corriente estable para servo. |
| SG90 Left | GND | GND | GND | Alimentacion | GND comun con Arduino. |
| SG90 Left | Signal | D9 | SERVO_LEFT | PWM manual | 1700 us avanza; 1300 us retrocede. |
| SG90 Right | VCC | VCC | VCC_SERVO/5V | Alimentacion | Verificar corriente estable para servo. |
| SG90 Right | GND | GND | GND | Alimentacion | GND comun con Arduino. |
| SG90 Right | Signal | D10 | SERVO_RIGHT | PWM manual | Acompana invertido por montaje: 1300 us para avance. |

## Alimentacion

- Todos los modulos comparten GND comun.
- La Shield de expansion organiza conexiones, pero no aumenta la capacidad de corriente del Arduino Nano.
- Si los servos SG90 presentan reinicios o vibracion, alimentar servos con fuente estable de 5 V y unir GND con Arduino.

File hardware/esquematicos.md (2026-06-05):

# Esquematicos

El proyecto KiCad se encuentra en `hardware/kicad/robot_minisumo.kicad_pro`.

El esquematico representa el montaje real sobre Arduino Nano Expansion I/O Shield:

- Arduino Nano.
- Shield de expansion.
- HC-SR04 en D4/D5.
- TCRT5000 Left D3, Right D2, Back D0.
- SG90 Left D9, Right D10.
- Buzzer KY-012 D7.
- Alimentacion VCC_5V/VCC_SERVO y GND comun.

## Notas

- Todos los modulos comparten GND comun.
- La Shield organiza conexiones, pero no aumenta la capacidad de corriente.
- Verificar alimentacion estable de servos SG90.
- D0/D1 son RX/TX Serial; el prototipo usa D0 para TCRT Back por conexion real probada.

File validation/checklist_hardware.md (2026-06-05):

# Checklist De Hardware

| Verificacion | Estado | Nota |
| --- | --- | --- |
| D1 libre; D0 usado por TCRT Back | Completo documental | Reservados para RX/TX Serial |
| TCRT Left en D2 | Pendiente hardware | Validar DO |
| TCRT Right en D3 | Pendiente hardware | Reasignado desde D1 |
| TCRT Back en D6 | Pendiente hardware | Reasignado desde D0 |
| HC-SR04 Trig/Echo D4/D5 | Pendiente hardware | Validar lectura |
| Buzzer D7 | Pendiente hardware | Validar polaridad |
| SG90 D9/D10 | Pendiente hardware | Confirmar rotacion continua |
| GND comun | Pendiente hardware | Obligatorio |
| Fuente de servos | Pendiente hardware | Usar externa si hay reinicios |

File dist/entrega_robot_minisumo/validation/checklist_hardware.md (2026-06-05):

# Checklist Hardware

Estado del prototipo fisico: **funcional**.

- [x] Arduino Nano energiza correctamente.
- [x] Shield de expansion usada como distribuidor de pines, VCC y GND.
- [x] GND comun para sensores, buzzer y servos.
- [x] HC-SR04 en Trig D4 / Echo D5 probado con lecturas de distancia.
- [x] TCRT5000 Left en D3 probado.
- [x] TCRT5000 Right en D2 probado.
- [x] TCRT5000 Back en D0 probado.
- [x] Buzzer KY-012 en D7 probado.
- [x] SG90 Left en D9 probado.
- [x] SG90 Right en D10 probado.
- [x] Advertencia D0/RX documentada.
- [x] Alimentacion funcional para prueba fisica.

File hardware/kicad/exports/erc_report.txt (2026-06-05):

ERC no ejecutado automaticamente.

Motivo: kicad-cli no esta disponible en PATH durante la consolidacion final.

Procedimiento manual:
1. Abrir hardware/kicad/robot_minisumo.kicad_pro en KiCad.
2. Abrir el esquematico robot_minisumo.kicad_sch.
3. Ejecutar Inspeccion electrica / ERC.
4. Exportar reporte, PDF y SVG a hardware/kicad/exports/.

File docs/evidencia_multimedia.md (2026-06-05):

# Evidencia multimedia del Robot Minisumo

La evidencia multimedia documenta el prototipo fisico, su cableado, pruebas de componentes, panel web y funcionamiento final. Esta evidencia esta pensada para acompanar la entrega academica y para explicar el robot durante la grabacion del video final.

## Evidencia visual principal

| Evidencia | Archivo | Que muestra |
| --- | --- | --- |
| Diagrama de conexiones | `assets/images/conexiones/robot_minisumo_conexiones_diagrama_final_01.png` | Pinout real: TCRT5000 Left D3, Right D2, Back D0, HC-SR04 D4/D5, buzzer D7, servos D9/D10. |
| Montaje frontal | `assets/images/montaje/robot_minisumo_montaje_frontal_hcsr04_01.jpg` | Carcasa del prototipo y sensor HC-SR04 al frente. |
| Montaje lateral izquierdo | `assets/images/montaje/robot_minisumo_montaje_lateral_izquierdo_01.jpg` | Rueda, porta pilas, shield y sensores activos. |
| Montaje lateral derecho | `assets/images/montaje/robot_minisumo_montaje_lateral_derecho_01.jpg` | Vista lateral opuesta del ensamble fisico. |
| Montaje posterior | `assets/images/montaje/robot_minisumo_montaje_posterior_electronica_01.jpg` | Arduino Nano, shield, buzzer y cableado posterior. |
| Prueba superior | `assets/images/pruebas/robot_minisumo_pruebas_alimentacion_sensores_01.jpg` | Alimentacion, cableado y modulos encendidos. |
| Panel web | `assets/images/panel/robot_minisumo_panel_monitoreo_desktop_01.png` | Panel minimalista de monitoreo en vista laptop. |

## Evidencia en video

| Video | Duracion | Tamano | Uso recomendado |
| --- | --- | --- | --- |
| `assets/videos/pruebas/robot_minisumo_pruebas_buzzer_arranque_01.mp4` | 00:00:02 | 0.50 MB | Mostrar senal sonora de arranque o prueba de buzzer. |
| `assets/videos/pruebas/robot_minisumo_pruebas_movimiento_servos_01.mp4` | 00:00:09 | 2.12 MB | Mostrar movimiento de servos/motores. |
| `assets/videos/pruebas/robot_minisumo_pruebas_sensores_linea_01.mp4` | 00:00:06 | 1.35 MB | Mostrar respuesta de sensores TCRT5000. |
| `assets/videos/pruebas/robot_minisumo_pruebas_ultrasonico_busqueda_01.mp4` | 00:00:09 | 2.18 MB | Mostrar busqueda o deteccion con HC-SR04. |
| `assets/videos/demo_final/robot_minisumo_demo_funcionamiento_final_01.mp4` | 00:00:15 | 3.39 MB | Video principal para demostrar el robot funcionando. |

## Uso durante la grabacion final

1. Abrir `http://localhost:8080/web-control/` o `web-control/index.html`.
2. Colocar la laptop junto al robot para que el panel sea visible durante la explicacion.
3. Usar modo real si el Arduino esta conectado por Web Serial.
4. Usar modo demo si se necesita explicar un estado sin depender de la lectura real en ese momento.
5. Reproducir o mostrar los videos de `assets/videos/demo_final/` y `assets/videos/pruebas/` como evidencia de funcionamiento.

## Limitaciones

- Los videos estan integrados como evidencia local del repositorio; para una publicacion publica se recomienda revisar que no incluyan informacion personal o fondo no deseado.
- La comunicacion Web Serial depende de navegador compatible y permiso manual del usuario para seleccionar el puerto.
- La carpeta `assets/images/kicad/` queda reservada porque no habia una imagen KiCad adicional lista para copiar sin cambiar los archivos de KiCad.

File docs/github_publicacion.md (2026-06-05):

# Publicacion en GitHub y multimedia

Fecha: 2026-06-05

## Revision de tamanos

| Archivo | Tamano | Recomendacion |
| --- | --- | --- |
| `assets/videos/demo_final/robot_minisumo_demo_funcionamiento_final_01.mp4` | 3.39 MB | Apto para commit normal. |
| `assets/videos/pruebas/robot_minisumo_pruebas_buzzer_arranque_01.mp4` | 0.50 MB | Apto para commit normal. |
| `assets/videos/pruebas/robot_minisumo_pruebas_movimiento_servos_01.mp4` | 2.12 MB | Apto para commit normal. |
| `assets/videos/pruebas/robot_minisumo_pruebas_sensores_linea_01.mp4` | 1.35 MB | Apto para commit normal. |
| `assets/videos/pruebas/robot_minisumo_pruebas_ultrasonico_busqueda_01.mp4` | 2.18 MB | Apto para commit normal. |

El video mas grande pesa 3.39 MB, por debajo de los limites practicos de GitHub para este proyecto academico. No se habilito Git LFS.

## Recomendacion

- Mantener estos videos en el repositorio porque son ligeros y documentan el prototipo funcional.
- Si en el futuro se agregan videos mayores a 50 MB, considerar comprimirlos o publicarlos como release asset.
- Si un archivo supera 100 MB, GitHub puede rechazar el push; en ese caso no hacer commit del video y documentar un enlace externo o usar GitHub Releases.
- Antes de publicar el repositorio, revisar que fotos y videos no incluyan datos personales, rostros, ubicaciones o informacion no deseada en el fondo.

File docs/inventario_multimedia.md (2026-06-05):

# Inventario multimedia

Fecha: 2026-06-05
Proyecto: Robot Minisumo

Este inventario organiza la evidencia visual y de video del prototipo funcional. Los archivos originales de la carpeta externa `C:/Users/alvar/Downloads/Robot sumo Assets/` no fueron borrados; se copiaron al proyecto con nombres normalizados, en minusculas, sin espacios ni acentos.

## Estructura final

| Carpeta | Uso |
| --- | --- |
| `assets/images/conexiones/` | Diagramas finales de conexion. |
| `assets/images/montaje/` | Fotografias del montaje fisico del prototipo. |
| `assets/images/pruebas/` | Fotografias de pruebas y componentes activos. |
| `assets/images/panel/` | Capturas del panel web de monitoreo. |
| `assets/images/kicad/` | Reservado para futuras capturas/exportaciones KiCad. |
| `assets/videos/pruebas/` | Videos cortos de pruebas por componente o comportamiento. |
| `assets/videos/demo_final/` | Video principal de funcionamiento del robot. |

## Evidencia integrada

| Archivo final | Origen | Tipo | Tamano | Duracion / dimensiones | Uso |
| --- | --- | --- | --- | --- | --- |
| `assets/images/conexiones/robot_minisumo_conexiones_diagrama_final_01.png` | `diagrama de conexiones.png` | Imagen | 641 KB | 1242x817 | Diagrama final de cableado real. |
| `assets/images/montaje/robot_minisumo_montaje_frontal_hcsr04_01.jpg` | `WhatsApp Image 2026-06-05 at 3.39.11 PM.jpeg` | Imagen | 102 KB | 1280x963 | Vista frontal con HC-SR04. |
| `assets/images/montaje/robot_minisumo_montaje_lateral_izquierdo_01.jpg` | `WhatsApp Image 2026-06-05 at 3.39.10 PM.jpeg` | Imagen | 112 KB | 1280x963 | Vista lateral del montaje, alimentacion y rueda. |
| `assets/images/montaje/robot_minisumo_montaje_lateral_derecho_01.jpg` | `WhatsApp Image 2026-06-05 at 3.39.10 PM (1).jpeg` | Imagen | 102 KB | 1280x963 | Vista lateral opuesta del prototipo. |
| `assets/images/montaje/robot_minisumo_montaje_posterior_electronica_01.jpg` | `WhatsApp Image 2026-06-05 at 3.39.10 PM (2).jpeg` | Imagen | 107 KB | 1280x963 | Vista posterior con Arduino Nano, shield y buzzer. |
| `assets/images/pruebas/robot_minisumo_pruebas_alimentacion_sensores_01.jpg` | `WhatsApp Image 2026-06-05 at 3.39.11 PM (1).jpeg` | Imagen | 137 KB | 963x1280 | Vista superior con sensores/alimentacion activos. |
| `assets/images/panel/robot_minisumo_panel_monitoreo_desktop_01.png` | Captura generada desde `http://localhost:8080/web-control/` | Imagen | 59 KB | 1366x768 | Captura principal del panel en formato laptop. |
| `assets/images/panel/robot_minisumo_panel_monitoreo_demo_01.png` | Captura del navegador integrado | Imagen | 27 KB | 304x550 | Captura responsiva estrecha del panel en modo demo. |
| `assets/videos/pruebas/robot_minisumo_pruebas_buzzer_arranque_01.mp4` | `WhatsApp Video 2026-06-05 at 3.39.00 PM (1).mp4` | Video | 0.50 MB | 00:00:02 | Prueba corta de arranque/buzzer. |
| `assets/videos/pruebas/robot_minisumo_pruebas_movimiento_servos_01.mp4` | `WhatsApp Video 2026-06-05 at 3.39.00 PM.mp4` | Video | 2.12 MB | 00:00:09 | Prueba de movimiento con servos SG90. |
| `assets/videos/pruebas/robot_minisumo_pruebas_sensores_linea_01.mp4` | `WhatsApp Video 2026-06-05 at 3.39.09 PM.mp4` | Video | 1.35 MB | 00:00:06 | Prueba de sensores de linea / borde. |
| `assets/videos/pruebas/robot_minisumo_pruebas_ultrasonico_busqueda_01.mp4` | `WhatsApp Video 2026-06-05 at 3.39.10 PM (1).mp4` | Video | 2.18 MB | 00:00:09 | Prueba de busqueda con HC-SR04. |
| `assets/videos/demo_final/robot_minisumo_demo_funcionamiento_final_01.mp4` | `WhatsApp Video 2026-06-05 at 3.39.10 PM.mp4` | Video | 3.39 MB | 00:00:15 | Demostracion final del robot funcional. |

## Copias para reporte y entrega

| Destino | Contenido |
| --- | --- |
| `report/assets/` | Imagenes necesarias para el reporte academico: diagrama, fotos del prototipo y captura del panel. |
| `dist/entrega_robot_minisumo/assets/` | Copia completa de la evidencia final, incluyendo imagenes y videos. |

## Multimedia existente antes de organizar

| Ruta existente | Estado | Accion |
| --- | --- | --- |
| `docs/assets/diagrama_conexiones_final.png` | Evidencia documental previa. | Se conserva. |
| `docs/assets/diagrama_conexiones.png` | Copia previa del diagrama. | Se conserva. |
| `hardware/assets/diagrama_conexiones_final.png` | Evidencia hardware previa. | Se conserva. |
| `report/assets/diagrama_conexiones_final.png` | Evidencia previa en reporte. | Se conserva. |
| `web-control/assets/diagrama_conexiones_final.png` | Recurso usado por panel. | Se conserva. |
| `dist/entrega_robot_minisumo/.../diagrama_conexiones*.png` | Copias previas de entrega. | Se conserva. |
| `references/components/*` | Imagenes tecnicas de componentes. | Se conservan como referencia tecnica. |
| `archive/legacy_20260605/*` | Material archivado anterior. | Se conserva. |

## Observaciones

- No se elimino evidencia util del proyecto.
- No se detectaron videos pesados para GitHub: el mayor archivo integrado pesa 3.39 MB.
- No se habilito Git LFS porque no fue necesario para estos tamanos.
- La carpeta `assets/images/kicad/` queda preparada con `.gitkeep`; no se encontraron exportaciones KiCad en imagen para copiar sin modificar KiCad.

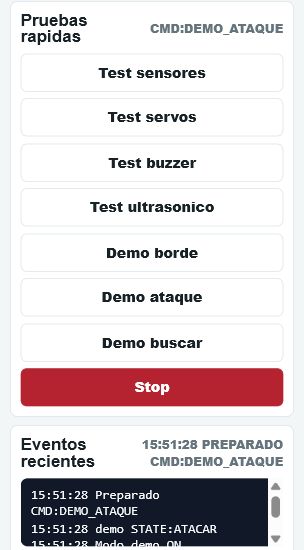
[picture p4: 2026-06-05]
report/assets/robot_minisumo_panel_monitoreo_demo_01.png

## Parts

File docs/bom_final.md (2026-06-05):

# BOM Final Robot Minisumo

Fuente valida: `BOM_Robot_Minisumo.xlsx` anexo, hoja `Componentes_Minisumo`.

Estado del prototipo fisico: **funcional**. La version final usa servomotores SG90 RC 9g, no motores DC N20.

| Cantidad | Componente | Modelo | Funcion en el robot | Voltaje | Observaciones |
| --- | --- | --- | --- | --- | --- |
| 1 (EL DE 4) | Porta Pilas AA Con Plug Para 4/6 Pilas | Porta-Pilas AA | Fuente portatil para alimentar el robot mediante la Shield. | 4 pilas AA con conector 9V | Dimensiones: Largo: 57.6mm Ancho: 61.9mm Espesor: 15mm Longitud del cable: 11 cm Plug de salida: 5.5 x 2.5 mm Peso: 16g Costo fuente: $17.0 |
| 1.0 | Paquete De 4 Pilas Alcalinas AA | Pilas-AA | Energia para el porta pilas AA. | Voltaje: 1.5 Volts | Dimensiones: 14 Ø mm x 50 mm Peso: 100g Costo fuente: $64.0 |
| 3.0 | Sensor Seguidor de Linea TCRT5000 Optico Infrarrojo 3.3 V a 5 V | TCRT5000 | Deteccion de borde de dohyo con tres sensores Left, Right y Back. | 3.3 V a 5 V | Dimensiones: 31 mm × 13 mm × 2 mm Peso: 3g Costo fuente: $60.0 |
| 2.0 | Sensor Ultrasónico HC-SR04 | HC-SR04 | Componente de soporte del robot. | 5V DC | Dimensiones: 45 x 20 x 15 mm Peso: 9g Costo fuente: $28.0 La conexion final usa un sensor frontal; la BOM conserva las unidades anexadas. |
| 2.0 | Buzzer Activo KY-012 | Buzzer-Activo | Indicador sonoro de arranque, ataque y evasion. | 3.5 a 5.5 V | Dimensiones: 18 mm x 15 mm x 15 mm Peso: 3g Costo fuente: $15.0 La conexion final usa un buzzer; la BOM conserva las unidades anexadas. |
| 1.0 | Arduino Nano V3 + cable USB | Arduino-Nano-v3 | Control principal de lectura de sensores y actuadores. | 7V a 12V | Dimensiones: 43.3 mm x 18 mm Peso: 6g Costo fuente: $122.0 |
| 1.0 | Shield para Arduino Nano Expansion I/O | Shield_Arduino_Nano | Control principal de lectura de sensores y actuadores. | 4.8V a 12V (Power jack) | Dimensiones: 60 mm x 55 mm x 10 mm Peso: 20.4 g Costo fuente: $44.0 |
| 2.0 | Servomotor SG90 RC 9g | Servomotor-SG90 | Traccion diferencial del robot con SG90 confirmados funcionales. | 4.8V a 12V | Dimensiones: 22.8mm x 12.3mm x 22.5mm Peso: 13 g Costo fuente: $40.0 SG90 confirmados en pruebas: D9 1700 us avanza y 1300 us retrocede. |
| 2.0 | Llantas de plástico | Llantas-Goma | Contacto mecanico de traccion para los servos. | - | Dimensiones: 7 cm con un ancho de 2.54 cm Peso: 19 g Costo fuente: $50.0 |
| 1-HH/1MH/1MM (uNO DE CADA UNO) | Cables Dupont Largos 20cm HH MH MM | Cables-Dupont | Cableado de senales, VCC y GND entre modulos y Shield. | - | Dimensiones: 20 cm Peso: 32 g Costo fuente: $22.0 |

## Notas de control de versiones

- La informacion anterior basada en motores DC N20 o driver de motores queda como antecedente archivado en `archive/legacy_20260605/`.
- Los servos SG90 fueron probados fisicamente: D9 avanza con 1700 us y retrocede con 1300 us; D10 acompana en sentido invertido por el montaje.
- Todos los modulos deben compartir GND comun.

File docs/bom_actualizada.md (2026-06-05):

# BOM Actualizada

| Componente | Cantidad BOM | Cantidad usada | Alimentacion | Nota |
| --- | ---: | ---: | --- | --- |
| Porta Pilas AA con plug | 1 | 1 | 4 pilas AA | Alimentacion mediante Shield |
| Pilas alcalinas AA | 1 paquete | 1 paquete | 1.5 V por pila | Fuente primaria |
| TCRT5000 | 3 | 3 | 3.3 V a 5 V | Left, Right, Back |
| HC-SR04 | 2 | 1 | 5 V | La BOM incluye repuesto |
| Buzzer activo KY-012 | 2 | 1 | 3.5 V a 5.5 V | La BOM incluye repuesto |
| Arduino Nano V3 | 1 | 1 | USB/VIN | Control principal |
| Shield Arduino Nano Expansion I/O | 1 | 1 | Jack/VCC | Base de conexion |
| Servomotor SG90 RC 9g | 2 | 2 | 4.8 V a 6 V recomendado | Confirmar rotacion continua |
| Llantas de plastico | 2 | 2 | No aplica | Ruedas |
| Cables Dupont | 1 set | Varios | No aplica | Conexion |

PENDIENTE CRITICO: confirmar fisicamente si los SG90 son de rotacion continua.

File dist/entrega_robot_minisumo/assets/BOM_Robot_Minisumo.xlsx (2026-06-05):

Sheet: Componentes_Minisumo
| | Componente | Link | Costo | Cantidad | Dimensiones | Peso | Alimentación
 | Porta Pilas AA Con Plug Para 4/6 Pilas | Porta-Pilas AA (https://uelectronics.com/producto/porta-pilas-aa-con-plug-para-4-6-pilas-2/) | $17.00 | 1 (EL DE 4) | Largo: 57.6mm Ancho: 61.9mm Espesor: 15mm Longitud del cable: 11 cm Plug de salida: 5.5 x 2.5 mm | 16g | 4 pilas AA con conector 9V
 | Paquete De 4 Pilas Alcalinas AA | Pilas-AA (https://uelectronics.com/producto/paquete-de-4-pilas-alcalinas-aa-bat-aa4/) | $64.00 | 1 | 14 Ø mm x 50 mm | 100g | Voltaje: 1.5 Volts
 | Sensor Seguidor de Linea TCRT5000 Optico Infrarrojo 3.3 V a 5 V | TCRT5000 (https://www.amazon.com.mx/Sensor-Seguidor-TCRT5000-Optico-Infrarrojo/dp/B09MSQZ65B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) | $60.00 | 3 | 31 mm × 13 mm × 2 mm | 3g | 3.3 V a 5 V
 | Sensor Ultrasónico HC-SR04 | HC-SR04 (https://uelectronics.com/producto/sensor-ultrasonico-hc-sr04/) | $28.00 | 2 | 45 x 20 x 15 mm | 9g | 5V DC
 | Buzzer Activo KY-012 | Buzzer-Activo (https://uelectronics.com/producto/buzzer-activo-ky-012/) | $15.00 | 2 | 18 mm x 15 mm x 15 mm | 3g | 3.5 a 5.5 V
 | Arduino Nano V3 + cable USB | Arduino-Nano-v3 (https://www.amazon.com.mx/UNIT-ELECTRONICS-Cable-Compatible-Arduino/dp/B09MRFHR9C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) | $122.00 | 1 | 43.3 mm x 18 mm | 6g | 7V a 12V
 | Shield para Arduino Nano Expansion I/O | Shield_Arduino_Nano (https://uelectronics.com/producto/shield-para-arduino-nano-expansion-i-o/) | $44.00 | 1 | 60 mm x 55 mm x 10 mm | 20.4 g | 4.8V a 12V (Power jack)
 | Servomotor SG90 RC 9g | Servomotor-SG90 (https://uelectronics.com/producto/servomotor-sg90-rc-9g/) | $40 | 2 | 22.8mm x 12.3mm x 22.5mm | 13 g | 4.8V a 12V
 | Llantas de plástico | Llantas-Goma (https://www.steren.com.mx/llantas-de-plastico.html) | $50 | 2 | 7 cm con un ancho de 2.54 cm | 19 g | -
 | Cables Dupont Largos 20cm HH MH MM | Cables-Dupont (https://uelectronics.com/producto/cables-dupont-largos-20cm-hh-mh-mm/) | $22 | 1-HH/1MH/1MM (uNO DE CADA UNO) | 20 cm | 32 g | -

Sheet: Conexiones
 |  | Pines Shield para Arduino Nano Expansion I/O
 |  | Pines Digitales
Componente |  | GND | VCC | I/O | Número de Pin
Sensor Seguidor de Linea TCRT5000 Optico Infrarrojo
 | left | GND | VCC | DO | 3
 | right | GND | VCC | DO | 2
 | back | GND | VCC | DO | 0
Sensor Ultrasónico HC-SR04 |  | GND | VCC | Trig | 4
 |  |  |  | Echo | 5
Buzzer Activo KY-012 |  | GND | VCC | Señal | 7
Servomotor SG90 RC 9g | left | GND | VCC | Señal PWM | 9
 | right | GND | VCC | Señal PWM | 10

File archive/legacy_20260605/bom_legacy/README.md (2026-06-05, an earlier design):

# BOM del robot minisumo

Esta carpeta conserva la lista de materiales del proyecto.

| Archivo | Origen | Uso |
|---|---|---|
| `BOM_Robot_Minisumo.xlsx` | `C:\Users\alvar\Downloads\BOM_Robot_Minisumo (1).xlsx` | BOM real con costos, cantidades, dimensiones, peso y alimentacion |

Resumen:

- Costo total de componentes confirmados: 685.
- Driver de motores: pendiente obligatorio y no incluido en la BOM.
- El motor GA12-N20 tiene dimensiones erroneas en la BOM; deben validarse con imagen de referencia y vernier.

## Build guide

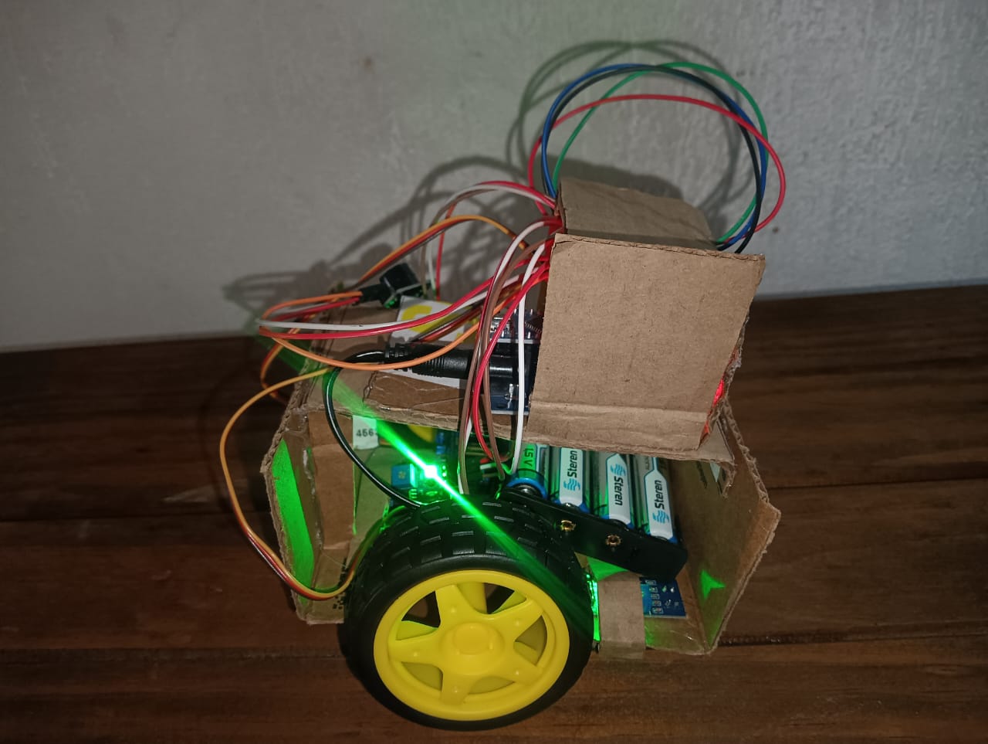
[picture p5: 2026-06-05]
dist/entrega_robot_minisumo/assets/images/montaje/robot_minisumo_montaje_lateral_derecho_01.jpg

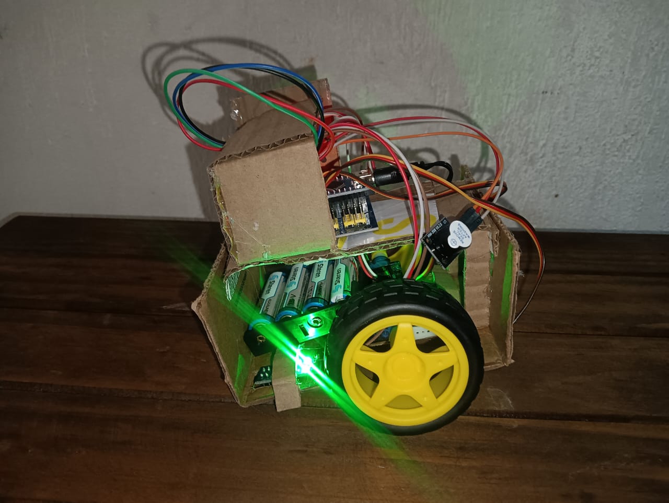
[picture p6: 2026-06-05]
dist/entrega_robot_minisumo/assets/robot_minisumo_montaje_lateral_izquierdo_01.jpg

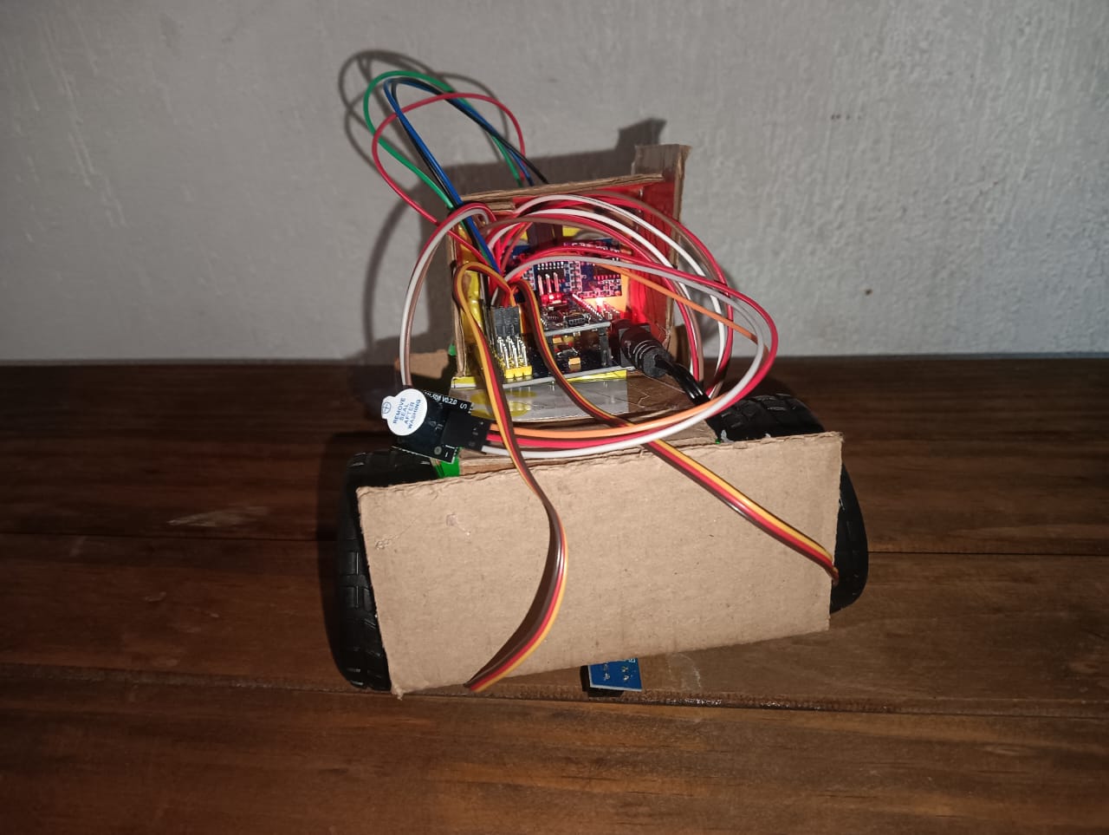
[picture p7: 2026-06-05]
report/assets/robot_minisumo_montaje_posterior_electronica_01.jpg

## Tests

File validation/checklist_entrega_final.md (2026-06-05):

# Checklist final de entrega

## Proyecto fisico
- [x] Robot funcional probado.
- [x] Sensores probados.
- [x] Servos probados.
- [x] Buzzer probado.
- [x] Alimentacion funcional en prueba.
- [x] GND comun validado en documentacion y cableado.

## Firmware
- [x] Sketches de prueba incluidos.
- [x] Firmware final incluido.
- [x] Firmware compilado en esta revision final.
- [x] Pinout coincide con conexiones finales.
- [x] Firmware final cargado en Arduino Nano.
- [x] Version `1.0.0-funcional` confirmada por Serial Monitor.
- [x] Firmware final emite telemetria Serial para panel web sin cambiar pinout.

## KiCad
- [x] Esquematico actualizado.
- [x] ERC ejecutado o documentado.
- [x] PDF/SVG exportado o documentado.
- [x] Diagrama coincide con conexion real.

## Reporte
- [x] Reporte `.md`.
- [x] Reporte `.tex`.
- [x] Reporte `.pdf`.
- [x] Investigacion documental.
- [x] BOM.
- [x] Lista de conexiones.
- [x] Diagramas.
- [x] Codigo.
- [x] Pseudocodigo.
- [x] Algoritmos.
- [x] Simulacion/validacion.
- [x] Conclusiones.

## GitHub
- [x] README publico sin datos personales academicos.
- [x] `.gitignore` correcto.
- [x] Commit final.
- [x] Repositorio creado.
- [x] Push realizado.

## Panel web de monitoreo

- [x] Muestra procesos del robot.
- [x] Muestra HC-SR04.
- [x] Muestra TCRT5000 Left.
- [x] Muestra TCRT5000 Right.
- [x] Muestra TCRT5000 Back.
- [x] Muestra servo/motor izquierdo.
- [x] Muestra servo/motor derecho.
- [x] Muestra buzzer.
- [x] Incluye modo demo.
- [x] Incluye registro de eventos.
- [x] Puede usarse para grabar video.
- [x] Documenta si Web Serial esta implementado o no.

## Panel para video final

- [x] Panel cabe en una sola pantalla.
- [x] Muestra accion actual.
- [x] Muestra procesos activos.
- [x] Muestra TCRT Left/Right/Back.
- [x] Muestra HC-SR04.
- [x] Muestra Servo Left/Right.
- [x] Muestra Buzzer.
- [x] Incluye pruebas rapidas.
- [x] Incluye modo demo.
- [x] Incluye log compacto.
- [x] Puede usarse durante la grabacion.

## Evidencia multimedia

- [x] Se creo `assets/images/conexiones/`.
- [x] Se creo `assets/images/montaje/`.
- [x] Se creo `assets/images/pruebas/`.
- [x] Se creo `assets/images/panel/`.
- [x] Se creo `assets/images/kicad/`.
- [x] Se creo `assets/videos/pruebas/`.
- [x] Se creo `assets/videos/demo_final/`.
- [x] Las fotos del prototipo fueron renombradas sin espacios ni acentos.
- [x] Los videos del prototipo fueron renombrados sin espacios ni acentos.
- [x] La evidencia fue copiada a `report/assets/`.
- [x] La evidencia fue copiada a `dist/entrega_robot_minisumo/assets/`.
- [x] Se documento `docs/inventario_multimedia.md`.
- [x] Se documento `docs/evidencia_multimedia.md`.
- [x] Se documento `validation/evidencia_funcionamiento.md`.
- [x] Se revisaron tamanos de video.
- [x] Se documento publicacion GitHub sin Git LFS en `docs/github_publicacion.md`.

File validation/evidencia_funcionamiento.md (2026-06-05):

# Evidencia de funcionamiento

Fecha: 2026-06-05

Este registro vincula la evidencia multimedia con el funcionamiento confirmado del Robot Minisumo.

## Evidencia fisica

| Archivo | Valida | Resultado |
| --- | --- | --- |
| `assets/images/montaje/robot_minisumo_montaje_frontal_hcsr04_01.jpg` | Sensor HC-SR04 instalado al frente. | Evidencia integrada. |
| `assets/images/montaje/robot_minisumo_montaje_posterior_electronica_01.jpg` | Arduino Nano, shield, buzzer y cableado. | Evidencia integrada. |
| `assets/images/pruebas/robot_minisumo_pruebas_alimentacion_sensores_01.jpg` | Alimentacion y sensores activos. | Evidencia integrada. |
| `assets/videos/pruebas/robot_minisumo_pruebas_buzzer_arranque_01.mp4` | Buzzer KY-012 / arranque. | Video integrado. |
| `assets/videos/pruebas/robot_minisumo_pruebas_movimiento_servos_01.mp4` | Movimiento de servos SG90. | Video integrado. |
| `assets/videos/pruebas/robot_minisumo_pruebas_sensores_linea_01.mp4` | Sensores TCRT5000 de linea. | Video integrado. |
| `assets/videos/pruebas/robot_minisumo_pruebas_ultrasonico_busqueda_01.mp4` | Busqueda/deteccion con HC-SR04. | Video integrado. |
| `assets/videos/demo_final/robot_minisumo_demo_funcionamiento_final_01.mp4` | Funcionamiento general del robot. | Video final integrado. |

## Evidencia de interfaz

| Archivo | Valida | Resultado |
| --- | --- | --- |
| `assets/images/panel/robot_minisumo_panel_monitoreo_desktop_01.png` | Panel web simple y minimalista para grabacion. | Captura 1366x768 integrada. |
| `assets/images/panel/robot_minisumo_panel_monitoreo_demo_01.png` | Vista responsiva estrecha del panel. | Captura integrada. |

## Resultado

- [x] La evidencia del prototipo fisico fue copiada al repositorio con nombres normalizados.
- [x] La evidencia de video fue separada en pruebas y demo final.
- [x] La evidencia del panel web fue capturada e integrada.
- [x] Los tamanos de video fueron revisados; ninguno requiere Git LFS.
- [x] La carpeta de entrega `dist/entrega_robot_minisumo/assets/` incluye copia de la evidencia.

## Pendientes reales

- Revisar visualmente cada video antes de publicar el repositorio en modo publico para confirmar que no incluya informacion personal o fondo no deseado.
- Si se graba un video final nuevo de mayor duracion, revisar su tamano antes de hacer commit.

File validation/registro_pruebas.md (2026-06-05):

# Registro De Pruebas

Fecha: 2026-06-05

| Prueba | Resultado esperado | Resultado observado | Estado |
| --- | --- | --- | --- |
| Buzzer KY-012 | Sonido intermitente al ejecutar test_buzzer | Sonido confirmado por usuario | Aprobado |
| HC-SR04 | Lecturas de distancia en cm | Lecturas observadas: 151, 152, 46, 47, 4, 11, 16, 7 y 6 cm | Aprobado |
| TCRT5000 Left | Cambio digital al detectar linea/borde | Los tres sensores funcionan con tabla final: Left D3, Right D2, Back D0 | Aprobado |
| TCRT5000 Right | Cambio digital al detectar linea/borde | Los tres sensores funcionan con tabla final: Left D3, Right D2, Back D0 | Aprobado |
| TCRT5000 Back | Cambio digital al detectar linea/borde | Funciona en D0; advertencia por RX Serial documentada | Aprobado |
| Servo D9 aislado | Movimiento adelante y atras | 1700 us adelanta y 1300 us atrasa | Aprobado |
| Servos D9/D10 conjunto | D9 avanza y D10 acompana sin quedarse quieto | D9 avanza, D10 acompana invertido por montaje, ninguno se queda quieto | Aprobado |
| Firmware final | Arranque serial y logica cargada | Firmware final cargado en COM8 y arranque serial observado | Aprobado |
| Version firmware final | Serial debe reportar nombre, version y estado | `Robot Minisumo Final`, `1.0.0-funcional`, `FUNCIONAL_PROBADO` capturados desde COM8 | Aprobado |
| Panel compacto - abrir vista | Debe cargar sin errores | Panel cargado desde `http://127.0.0.1:8080/web-control/` con titulo correcto y sin errores de consola | Aprobado |
| Panel compacto - una pantalla | Debe caber sin scroll en laptop | Edge headless con ventana 1366x768 reporto viewport interno 1336x639, sin overflow horizontal ni vertical | Aprobado |
| Panel compacto - estado general | Debe mostrar conexion, firmware, distancia, accion y modo | Los cinco indicadores aparecen en encabezado compacto | Aprobado |
| Panel compacto - componentes | Debe mostrar TCRT, HC-SR04, servos, buzzer y movimiento | Tarjetas compactas actualizadas visualmente | Aprobado |
| Panel compacto - pruebas rapidas | Debe incluir Test sensores, servos, buzzer, ultrasonico, demos y Stop | Ocho botones disponibles y vinculados a `CMD:*` | Aprobado |
| Panel compacto - modo demo | Debe indicar estados simulados | Aviso `Modo demo: los estados son simulados desde el panel` visible al activar demo | Aprobado |
| Panel compacto - Demo borde | Debe marcar borde, evasion, retroceso y buzzer | TCRT Left en BORDE, proceso evadir borde, movimiento retroceso y log actualizado | Aprobado |
| Panel compacto - Demo ataque | Debe mostrar oponente cerca, ataque y motores activos | Distancia 18 cm, accion atacar, servos en ataque y log actualizado | Aprobado |
| Panel compacto - Demo buscar | Debe mostrar busqueda/giro | Accion buscar, motores girando y log actualizado | Aprobado |
| Panel compacto - Stop | Debe detener motores visualmente | Accion detenido, servos STOP, movimiento detenido y log actualizado | Aprobado |
| Panel compacto - Web Serial | Debe leer telemetria y enviar comandos `CMD:*` | Integracion implementada; prueba fisica real por Web Serial queda pendiente de conectar Arduino en navegador compatible | Pendiente fisico |
| Robot fisico | Prototipo opera con sensores y actuadores finales | Estado reportado por usuario: robot fisico funcional | Aprobado |

## Evidencia textual

- Usuario confirmo que los tres sensores funcionan con la tabla final de conexiones.
- Usuario confirmo que D9 avanza y D10 acompana; D10 gira al reves por montaje y ninguno se queda quieto.
- Usuario confirmo calibracion D9: 1700 us adelanta y 1300 us atrasa.
- Firmware final se cargo en COM8 y mostro arranque serial correcto.
- Version final confirmada por Serial: `1.0.0-funcional`.
- Panel compacto probado en navegador integrado con modo demo y sin errores de consola.
- Web Serial fue implementado para lectura de telemetria y envio de comandos `CMD:*`; no se declaro prueba fisica real porque no se conecto Arduino desde el navegador durante esta validacion.

## Pruebas de evidencia multimedia

| Prueba | Resultado esperado | Resultado observado | Estado |
| --- | --- | --- | --- |
| Inventario multimedia | Debe listar origen, nombre final y uso | `docs/inventario_multimedia.md` creado con imagenes, videos, tamanos y duraciones | Aprobado |
| Estructura de assets | Debe incluir imagenes y videos separados por categoria | Carpetas `assets/images/*` y `assets/videos/*` creadas | Aprobado |
| Copia a reporte | El reporte debe tener imagenes locales | Fotos, diagrama y captura del panel copiadas a `report/assets/` | Aprobado |
| Copia a entrega | `dist/entrega_robot_minisumo/assets/` debe incluir evidencia final | Imagenes y videos copiados a `dist/entrega_robot_minisumo/assets/` | Aprobado |
| Tamanos de video | Ningun video debe ser demasiado pesado para GitHub | Video mayor: 3.39 MB; no requiere Git LFS | Aprobado |
| Captura del panel | Debe existir evidencia visual del panel | Captura 1366x768 creada en `assets/images/panel/` | Aprobado |

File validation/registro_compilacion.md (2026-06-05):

# Registro De Compilacion

Fecha: 2026-06-05

Herramienta:

```text
arduino-cli 1.5.0
Core arduino:avr 1.8.8 instalado
Puerto detectado: COM8 serial Serial Port (USB) Unknown
```

| Sketch | FQBN | Resultado | Error si aplica | Accion tomada |
| --- | --- | --- | --- | --- |
| `firmware/test_hcsr04` | `arduino:avr:nano` | Compila: 3188 bytes programa, 236 bytes RAM | No aplica | Verificado final |
| `firmware/test_tcrt5000` | `arduino:avr:nano` | Compila: 2544 bytes programa, 340 bytes RAM | No aplica | Verificado final con D3/D2/D0 |
| `firmware/test_servos` | `arduino:avr:nano` | Compila: 2322 bytes programa, 344 bytes RAM | No aplica | Verificado final con D9/D10 |
| `firmware/test_buzzer` | `arduino:avr:nano` | Compila: 1988 bytes programa, 208 bytes RAM | No aplica | Verificado final con D7 |
| `firmware/test_servo_d9` | `arduino:avr:nano` | Compila: 2192 bytes programa, 310 bytes RAM | No aplica | Incluido como evidencia de calibracion D9 |
| `firmware/robot_minisumo_final` | `arduino:avr:nano` | Compila: 8498 bytes programa, 874 bytes RAM | No aplica | Firmware final con telemetria Serial y comandos `CMD:*` para panel compacto verificado |

Nota: se mantiene generacion manual de pulsos para SG90; no se requiere `Servo.h`.

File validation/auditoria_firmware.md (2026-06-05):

# Auditoria Firmware

Fecha: 2026-06-05

Ruta auditada: `A:\robot-minisumo\firmware`

## Sketches identificados

| Archivo | Funcion | Estado | Accion |
| --- | --- | --- | --- |
| `firmware/robot_minisumo_final/robot_minisumo_final.ino` | Firmware final autonomo: lee HC-SR04, TCRT5000, controla SG90, buzzer, busqueda, ataque y evasion de borde | firmware final | Se agrego identificacion `Robot Minisumo Final`, version `1.0.0-funcional` y estado `FUNCIONAL_PROBADO` por Serial |
| `firmware/test_hcsr04/test_hcsr04.ino` | Prueba individual HC-SR04 Trig D4 / Echo D5 | prueba | Conservado |
| `firmware/test_tcrt5000/test_tcrt5000.ino` | Prueba individual TCRT5000 Left D3, Right D2, Back D0 | prueba | Conservado con advertencia D0/RX |
| `firmware/test_servos/test_servos.ino` | Prueba conjunta servos SG90 D9/D10 con pulsos manuales | prueba | Conservado |
| `firmware/test_servo_d9/test_servo_d9.ino` | Prueba aislada de calibracion del servo D9 | prueba | Conservado como evidencia de calibracion |
| `firmware/test_buzzer/test_buzzer.ino` | Prueba individual buzzer KY-012 en D7 | prueba | Conservado |

## Versiones antiguas o duplicadas

No se encontraron duplicados del firmware funcional dentro de `firmware/`. No se movio ningun archivo a `archive/firmware/`.

## Verificacion de pinout final

| Senal | Pin en firmware | Pin en conexiones finales | Estado |
| --- | --- | --- | --- |
| `TCRT_LEFT` | D3 | D3 | Coincide |
| `TCRT_RIGHT` | D2 | D2 | Coincide |
| `TCRT_BACK` | D0 | D0 | Coincide, con advertencia RX Serial |
| `TRIG_HCSR04` | D4 | D4 | Coincide |
| `ECHO_HCSR04` | D5 | D5 | Coincide |
| `BUZZER_SIG` | D7 | D7 | Coincide |
| `SERVO_LEFT` | D9 | D9 | Coincide |
| `SERVO_RIGHT` | D10 | D10 | Coincide |

## Riesgo D0/D1

D0 y D1 corresponden a RX/TX del Arduino Nano. El prototipo final usa D0 para `TCRT_BACK`, por lo que puede interferir con la carga de firmware o el Serial Monitor. Si ocurre, se debe desconectar temporalmente el cable DO del TCRT Back durante la carga o la depuracion Serial.

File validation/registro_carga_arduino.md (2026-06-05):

# Registro De Carga Arduino

Fecha: 2026-06-05

Herramienta usada:

```text
A:\robot-minisumo\tools\arduino-cli\arduino-cli.exe
arduino-cli 1.5.0
Core arduino:avr 1.8.8
```

## Puerto detectado

`arduino-cli board list` detecto:

```text
COM8 serial Serial Port (USB) Unknown
```

## Resultado de carga y confirmacion

| Elemento | Resultado |
| --- | --- |
| Puerto detectado | COM8 |
| FQBN usado | `arduino:avr:nano` |
| Compilacion | OK |
| Carga al Arduino | OK |
| Version reportada por Serial | `1.0.0-funcional` |
| Estado final | Cargado y confirmado |

## Version confirmada por Serial

Lectura capturada desde COM8 a 9600 baudios:

```text
Robot Minisumo Final
1.0.0-funcional
FUNCIONAL_PROBADO
Robot Minisumo - Pinout real: TCRT L/R/B D3/D2/D0
Prototipo fisico funcional: SG90 D9/D10 y sensores finales confirmados.
Advertencia: TCRT Back usa D0/RX; desconectar para cargar firmware si es necesario.
```

## Nota D0/RX

El prototipo final usa D0 para `TCRT_BACK`. D0 corresponde a RX Serial del Arduino Nano y puede interferir con carga o depuracion; si ocurre, desconectar temporalmente el cable DO del TCRT Back.

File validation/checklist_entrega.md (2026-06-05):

# Checklist De Entrega

| Item | Estado | Evidencia |
| --- | --- | --- |
| Ruta `A:\robot-minisumo` validada | Completo | `docs/auditoria_inicial.md` |
| README actualizado | Completo | `README.md` |
| `.gitignore` creado | Completo | `.gitignore` |
| BOM actualizada | Completo | `docs/bom_actualizada.md` |
| Lista de conexiones sin D0/D1 | Completo | `docs/lista_conexiones.md` |
| Firmware final | Completo | `firmware/robot_minisumo_final` |
| Pruebas individuales | Completo | `firmware/test_*` |
| KiCad documental | Completo | `hardware/kicad` |
| ERC/exportaciones | Pendiente | Requiere `kicad-cli` |
| Reporte academico | Completo | `report/` |
| Web control | Completo | `web-control/` |
| Git | Completo | Commit inicial creado |
| GitHub | Completo | Repo privado creado y push realizado |

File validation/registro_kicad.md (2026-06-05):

# Registro KiCad

Estado:

| Item | Estado |
| --- | --- |
| Proyecto KiCad | Creado |
| Esquematico documental | Creado |
| ERC | Pendiente |
| Exportacion PDF/SVG | Pendiente |

Procedimiento documentado en `hardware/kicad/exports/README.md`.

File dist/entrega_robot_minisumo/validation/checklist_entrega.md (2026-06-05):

# Checklist De Entrega

| Elemento | Estado | Evidencia |
| --- | --- | --- |
| BOM final | Completo | `docs/bom_final.md` |
| Lista de conexiones final | Completo | `docs/lista_conexiones_final.md` |
| Imagen final de conexiones | Completo | `docs/assets/diagrama_conexiones_final.png` |
| Firmware final | Completo | `firmware/robot_minisumo_final/robot_minisumo_final.ino` |
| Sketches de prueba | Completo | `firmware/test_*` |
| Compilacion Arduino | Completo | `validation/registro_compilacion.md` |
| Pruebas fisicas | Completo | `validation/registro_pruebas.md` |
| KiCad documental | Completo | `hardware/kicad/robot_minisumo.kicad_sch` |
| ERC/exportacion KiCad | Documentado | `validation/registro_kicad.md` |
| Reporte academico | Completo | `report/reporte_robot_minisumo.*` |
| README publico | Completo | `README.md` sin datos academicos personales |
| Carpeta dist | Completo | `dist/entrega_robot_minisumo/` |

Pinout final: TCRT Left D3, TCRT Right D2, TCRT Back D0, HC-SR04 D4/D5, KY-012 D7, SG90 D9/D10.

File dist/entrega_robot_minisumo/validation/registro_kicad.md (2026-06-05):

# Registro KiCad

Fecha: 2026-06-05

| Item | Estado | Evidencia / accion |
| --- | --- | --- |
| Proyecto KiCad | Creado | `hardware/kicad/robot_minisumo.kicad_pro` |
| Esquematico documental | Actualizado | `hardware/kicad/robot_minisumo.kicad_sch` con pinout D3/D2/D0, D4/D5, D7, D9/D10 |
| Net labels | Documentadas | `VCC_5V`, `GND`, `TRIG_HCSR04`, `ECHO_HCSR04`, `TCRT_LEFT`, `TCRT_RIGHT`, `TCRT_BACK`, `SERVO_LEFT`, `SERVO_RIGHT`, `BUZZER_SIG` |
| ERC | No ejecutado automaticamente | `kicad-cli` no disponible en PATH |
| Exportacion PDF/SVG | No ejecutada automaticamente | `kicad-cli` no disponible en PATH |
| Procedimiento manual | Documentado | `hardware/kicad/exports/README.md` |

Pendiente real: abrir el proyecto en KiCad de escritorio y ejecutar Inspeccion electrica, exportacion PDF y exportacion SVG si se requiere evidencia grafica oficial de KiCad.

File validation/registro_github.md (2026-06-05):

# Registro Git Y GitHub

Fecha: 2026-06-05

| Item | Resultado |
| --- | --- |
| Git local | Inicializado |
| Commit inicial | `dcda338 Initial robot minisumo project structure` |
| GitHub CLI | Autenticado como `Angel-Alvarez-Dev` |
| Repositorio remoto | `https://github.com/Angel-Alvarez-Dev/robot-minisumo` |
| Visibilidad | Privado |
| Push | Completado a `origin/master` |

Nota: se uso repositorio privado como alternativa segura a publicar contenido completo en un repositorio publico.

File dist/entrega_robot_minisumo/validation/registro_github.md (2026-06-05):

# Registro GitHub

Fecha: 2026-06-05

| Item | Estado |
| --- | --- |
| GitHub CLI | Autenticado como `Angel-Alvarez-Dev` |
| Repositorio remoto | `https://github.com/Angel-Alvarez-Dev/robot-minisumo` |
| Visibilidad actual | PRIVATE |
| Rama local | `master` |
| README publico | Revisado sin datos academicos personales |
| Reporte/dist | Contienen datos academicos solo para entrega |
| Commit final | Preparado como `Finalize functional robot minisumo project` |
| Push final | Realizado a `origin/master` |

Nota: el repositorio se mantiene privado para no exponer los datos academicos incluidos en `report/` y `dist/entrega_robot_minisumo/`. Si se requiere publicarlo, revisar primero si esos documentos deben permanecer en el repositorio publico.

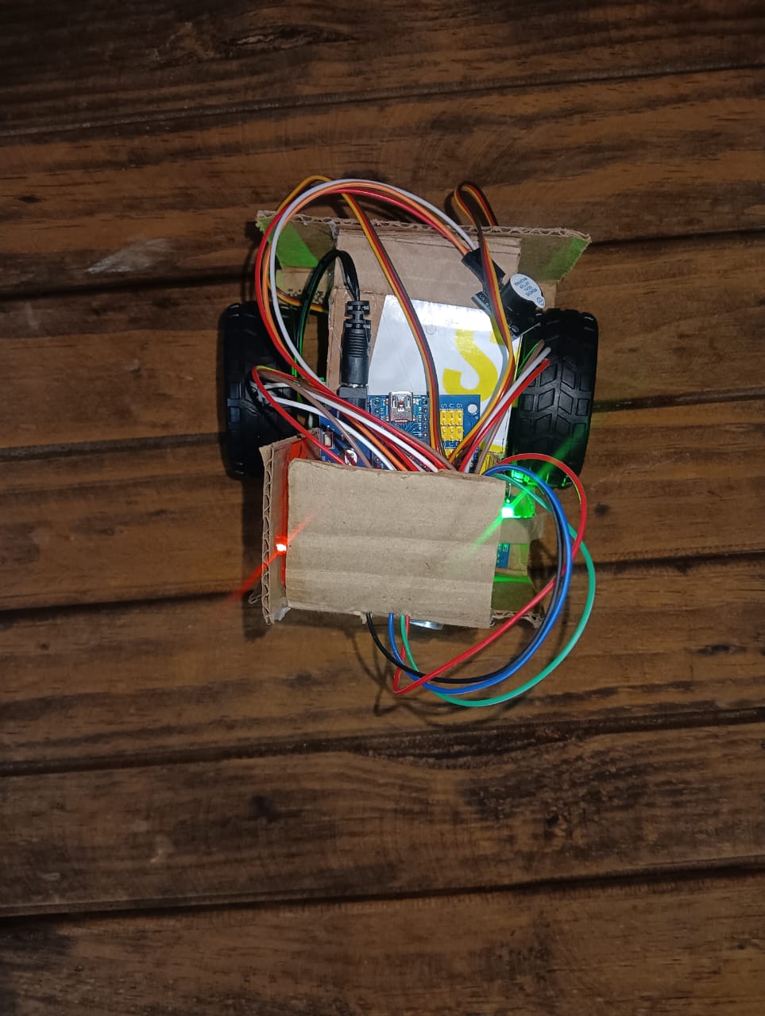
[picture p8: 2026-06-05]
dist/entrega_robot_minisumo/assets/images/pruebas/robot_minisumo_pruebas_alimentacion_sensores_01.jpg

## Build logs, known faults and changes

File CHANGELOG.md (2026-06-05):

# Changelog

## 2026-06-05 - Finalizacion funcional Robot Minisumo

### Verificado posteriormente

- Se agrego identificacion de firmware final: `Robot Minisumo Final`, `1.0.0-funcional`, `FUNCIONAL_PROBADO`.
- Se compilo y cargo `firmware/robot_minisumo_final/robot_minisumo_final.ino` en Arduino Nano por `COM8`.
- La version cargada fue confirmada por Serial Monitor.

### Agregado

- BOM final desde Excel anexo.
- Lista final de conexiones desde Excel e imagen final.
- Imagen `diagrama_conexiones_final.png` en docs, hardware, report y web-control.
- Auditoria final y checklist de entrega final.
- Reporte academico en Markdown, LaTeX y PDF.
- Panel web con estado Arduino por Web Serial API.
- Evidencia final de pruebas fisicas.

### Cambiado

- Pinout final real: TCRT Left D3, Right D2, Back D0; HC-SR04 D4/D5; KY-012 D7; SG90 D9/D10.
- README publico actualizado sin datos academicos personales.
- Firmware final documenta calibracion SG90 y advertencia D0/RX.
- Documentacion reemplaza antecedentes de motores DC N20 por version final con SG90.

### Estado

- Prototipo fisico funcional.
- KiCad documental actualizado.
- ERC/exportaciones KiCad dependen de disponibilidad de `kicad-cli`.

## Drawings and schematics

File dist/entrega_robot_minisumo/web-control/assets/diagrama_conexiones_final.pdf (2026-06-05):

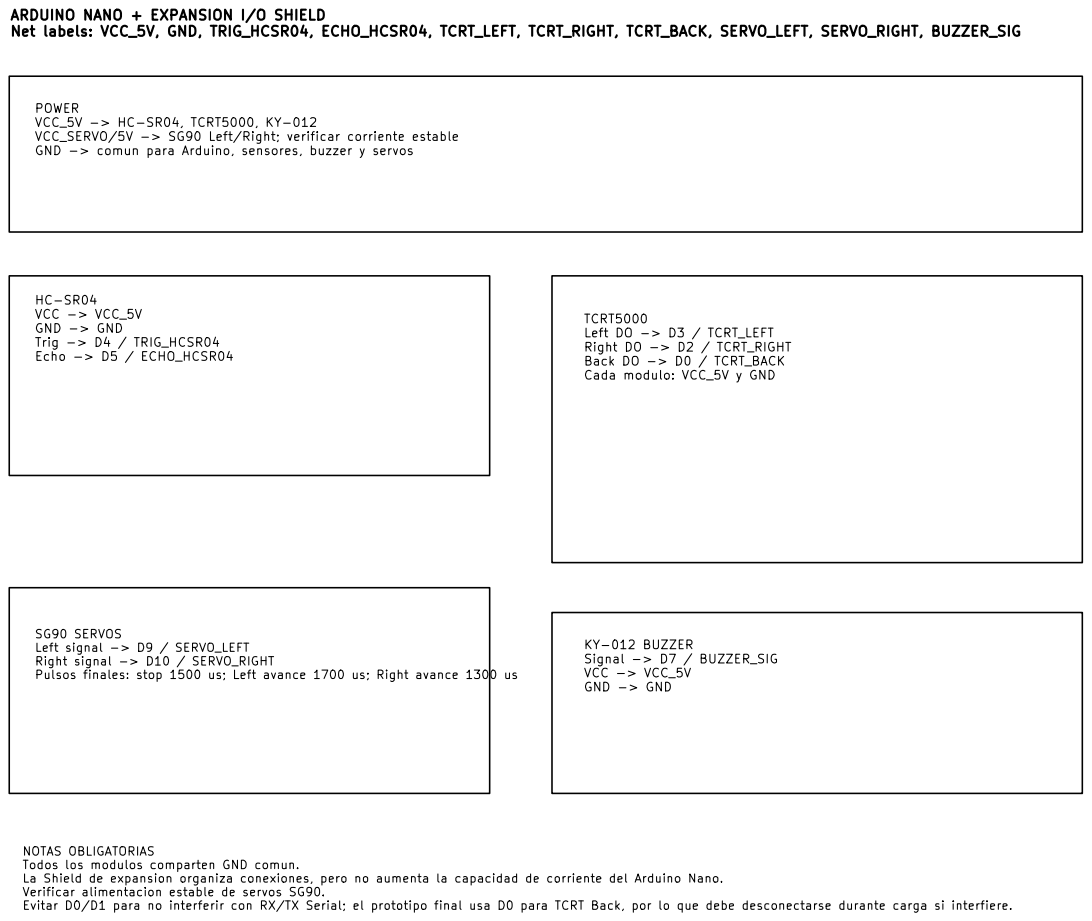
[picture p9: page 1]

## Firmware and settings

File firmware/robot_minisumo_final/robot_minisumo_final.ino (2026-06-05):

#define FIRMWARE_NAME "Robot Minisumo Final"
#define FIRMWARE_VERSION "1.0.0-funcional"
#define FIRMWARE_STATUS "FUNCIONAL_PROBADO"

const byte PIN_TCRT_LEFT = 3;
const byte PIN_TCRT_RIGHT = 2;
const byte PIN_TCRT_BACK = 0;
const byte PIN_TRIG_HCSR04 = 4;
const byte PIN_ECHO_HCSR04 = 5;
const byte PIN_BUZZER = 7;
const byte PIN_SERVO_LEFT = 9;
const byte PIN_SERVO_RIGHT = 10;

// Calibracion final probada:
// - TCRT5000 activo en LOW con los modulos conectados a D3/D2/D0.
// - D0 corresponde a RX Serial; desconectar TCRT Back durante carga si interfiere.
// - SG90 de rotacion continua: 1700 us avanza en D9, 1300 us retrocede.
const bool LINE_ACTIVE_LOW = true;
const unsigned int DISTANCIA_ATAQUE_CM = 35;
const unsigned int TIEMPO_ARRANQUE_MS = 3000;
const unsigned long PANEL_INTERVALO_MS = 250;

const int SERVO_STOP_US = 1500;
const int SERVO_LEFT_FORWARD_US = 1700;
const int SERVO_LEFT_REVERSE_US = 1300;
const int SERVO_RIGHT_FORWARD_US = 1300;
const int SERVO_RIGHT_REVERSE_US = 1700;
const unsigned long SERVO_PERIOD_US = 20000UL;

struct LecturaLinea {
  bool left;
  bool right;
  bool back;
};

int pulsoServoLeft = SERVO_STOP_US;
int pulsoServoRight = SERVO_STOP_US;
unsigned long ultimoPulsoServo = 0;
unsigned long ultimoEstadoPanel = 0;
unsigned long pausaPanelHasta = 0;
LecturaLinea ultimaLinea = {false, false, false};
long ultimaDistanciaCm = -1;
bool ultimoOponenteDetectado = false;
const char* estadoPanel = "INIT";
const char* motorLeftPanel = "DETENIDO";
const char* motorRightPanel = "DETENIDO";
const char* buzzerPanel = "OFF";

void configurarPines();
long leerUltrasonico();
LecturaLinea leerSensoresLinea();
bool leerLineaDigital(byte pin);
void avanzar();
void retroceder();
void girarIzquierda();
void girarDerecha();
void detenerRobot();
void buscarOponente();
void atacar();
void evitarBorde();
void sonarBuzzer();
void sonarBuzzer(unsigned int duracionMs);
void pruebaSensores();
void pruebaUltrasonico();
void pruebaServos();
void procesarComandoSerial();
void procesarComandoPanel(String cmd);
void actualizarServos();
void emitirPulsoServo(byte pin, int anchoUs);
void setServos(int leftUs, int rightUs);
void publicarEstadoPanel();

void setup() {
  Serial.begin(9600);
  Serial.setTimeout(20);
  configurarPines();
  detenerRobot();
  Serial.println(FIRMWARE_NAME);
  Serial.println(FIRMWARE_VERSION);
  Serial.println(FIRMWARE_STATUS);
  Serial.println("Robot Minisumo - Pinout real: TCRT L/R/B D3/D2/D0");
  Serial.println("Prototipo fisico funcional: SG90 D9/D10 y sensores finales confirmados.");
  Serial.println("Advertencia: TCRT Back usa D0/RX; desconectar para cargar firmware si es necesario.");
  estadoPanel = "START_WAIT";
  ultimaLinea = leerSensoresLinea();
  publicarEstadoPanel();
  sonarBuzzer(120);
  delay(TIEMPO_ARRANQUE_MS);
  estadoPanel = "BUSCAR";
  publicarEstadoPanel();
  sonarBuzzer(80);
}

void loop() {
  actualizarServos();
  procesarComandoSerial();

  if (millis() < pausaPanelHasta) {
    estadoPanel = "DETENER";
    detenerRobot();
    publicarEstadoPanel();
    return;
  }

  estadoPanel = "READ_LINE";
  LecturaLinea linea = leerSensoresLinea();
  ultimaLinea = linea;
  publicarEstadoPanel();
  if (linea.left || linea.right || linea.back) {
    estadoPanel = "EVITAR_BORDE";
    publicarEstadoPanel();
    evitarBorde();
    publicarEstadoPanel();
    return;
  }

  estadoPanel = "READ_ULTRA";
  long distancia = leerUltrasonico();
  ultimaDistanciaCm = distancia;
  ultimoOponenteDetectado = distancia > 0 && distancia <= DISTANCIA_ATAQUE_CM;
  publicarEstadoPanel();
  if (ultimoOponenteDetectado) {
    atacar();
  } else {
    buscarOponente();
  }
  publicarEstadoPanel();
}

void configurarPines() {
  pinMode(PIN_TCRT_LEFT, INPUT_PULLUP);
  pinMode(PIN_TCRT_RIGHT, INPUT_PULLUP);
  pinMode(PIN_TCRT_BACK, INPUT_PULLUP);
  pinMode(PIN_TRIG_HCSR04, OUTPUT);
  pinMode(PIN_ECHO_HCSR04, INPUT);
  pinMode(PIN_BUZZER, OUTPUT);
  pinMode(PIN_SERVO_LEFT, OUTPUT);
  pinMode(PIN_SERVO_RIGHT, OUTPUT);
  digitalWrite(PIN_TRIG_HCSR04, LOW);
  digitalWrite(PIN_BUZZER, LOW);
  digitalWrite(PIN_SERVO_LEFT, LOW);
  digitalWrite(PIN_SERVO_RIGHT, LOW);
}

long leerUltrasonico() {
  digitalWrite(PIN_TRIG_HCSR04, LOW);
  delayMicroseconds(2);
  digitalWrite(PIN_TRIG_HCSR04, HIGH);
  delayMicroseconds(10);
  digitalWrite(PIN_TRIG_HCSR04, LOW);
  unsigned long duracion = pulseIn(PIN_ECHO_HCSR04, HIGH, 25000UL);
  if (duracion == 0) return -1;
  return (long)(duracion * 0.0343 / 2.0);
}

LecturaLinea leerSensoresLinea() {
  LecturaLinea lectura;
  lectura.left = leerLineaDigital(PIN_TCRT_LEFT);
  lectura.right = leerLineaDigital(PIN_TCRT_RIGHT);
  lectura.back = leerLineaDigital(PIN_TCRT_BACK);
  return lectura;
}

bool leerLineaDigital(byte pin) {
  int valor = digitalRead(pin);
  return LINE_ACTIVE_LOW ? valor == LOW : valor == HIGH;
}

void avanzar() {
  setServos(SERVO_LEFT_FORWARD_US, SERVO_RIGHT_FORWARD_US);
  motorLeftPanel = "AVANZAR";
  motorRightPanel = "AVANZAR";
}

void retroceder() {
  setServos(SERVO_LEFT_REVERSE_US, SERVO_RIGHT_REVERSE_US);
  motorLeftPanel = "RETROCEDER";
  motorRightPanel = "RETROCEDER";
}

void girarIzquierda() {
  setServos(SERVO_LEFT_REVERSE_US, SERVO_RIGHT_FORWARD_US);
  motorLeftPanel = "RETROCEDER";
  motorRightPanel = "AVANZAR";
}

void girarDerecha() {
  setServos(SERVO_LEFT_FORWARD_US, SERVO_RIGHT_REVERSE_US);
  motorLeftPanel = "AVANZAR";
  motorRightPanel = "RETROCEDER";
}

void detenerRobot() {
  setServos(SERVO_STOP_US, SERVO_STOP_US);
  motorLeftPanel = "DETENIDO";
  motorRightPanel = "DETENIDO";
}

void buscarOponente() {
  estadoPanel = "BUSCAR";
  girarDerecha();
  publicarEstadoPanel();
  delay(80);
}

void atacar() {
  estadoPanel = "ATACAR";
  avanzar();
  motorLeftPanel = "ATAQUE";
  motorRightPanel = "ATAQUE";
  publicarEstadoPanel();
  sonarBuzzer(25);
  delay(120);
}

void evitarBorde() {
  estadoPanel = "EVITAR_BORDE";
  LecturaLinea linea = leerSensoresLinea();
  ultimaLinea = linea;
  sonarBuzzer(120);
  estadoPanel = "RETROCEDER";
  retroceder();
  publicarEstadoPanel();
  delay(350);
  if (linea.left && !linea.right) {
    estadoPanel = "GIRO_DERECHO";
    girarDerecha();
  } else if (linea.right && !linea.left) {
    estadoPanel = "GIRO_IZQUIERDO";
    girarIzquierda();
  } else {
    estadoPanel = "GIRO_DERECHO";
    girarDerecha();
  }
  publicarEstadoPanel();
  delay(linea.back ? 500 : 350);
  estadoPanel = "DETENER";
  detenerRobot();
  publicarEstadoPanel();
}

void sonarBuzzer(unsigned int duracionMs) {
  buzzerPanel = "ON";
  digitalWrite(PIN_BUZZER, HIGH);
  ultimoEstadoPanel = 0;
  publicarEstadoPanel();
  delay(duracionMs);
  digitalWrite(PIN_BUZZER, LOW);
  buzzerPanel = "OFF";
  ultimoEstadoPanel = 0;
  publicarEstadoPanel();
}

void sonarBuzzer() {
  sonarBuzzer(80);
}

void pruebaSensores() {
  long distancia = leerUltrasonico();
  LecturaLinea linea = leerSensoresLinea();
  ultimaDistanciaCm = distancia;
  ultimaLinea = linea;
  ultimoOponenteDetectado = distancia > 0 && distancia <= DISTANCIA_ATAQUE_CM;
  Serial.print("Distancia=");
  Serial.print(distancia);
  Serial.print(" L=");
  Serial.print(linea.left);
  Serial.print(" R=");
  Serial.print(linea.right);
  Serial.print(" B=");
  Serial.println(linea.back);
  ultimoEstadoPanel = 0;
  publicarEstadoPanel();
}

void pruebaUltrasonico() {
  long distancia = leerUltrasonico();
  ultimaDistanciaCm = distancia;
  ultimoOponenteDetectado = distancia > 0 && distancia <= DISTANCIA_ATAQUE_CM;
  estadoPanel = "READ_ULTRA";
  Serial.print("DIST_CM:");
  Serial.println(distancia);
  Serial.print("OPONENTE:");
  Serial.println(ultimoOponenteDetectado ? 1 : 0);
  ultimoEstadoPanel = 0;
  publicarEstadoPanel();
}

void pruebaServos() {
  avanzar();
  delay(500);
  detenerRobot();
  delay(300);
  retroceder();
  delay(500);
  detenerRobot();
}

void procesarComandoSerial() {
  if (!Serial.available()) return;
  String cmd = Serial.readStringUntil('\n');
  cmd.trim();
  if (cmd.length() == 0) return;

  if (cmd.startsWith("CMD:")) {
    procesarComandoPanel(cmd);
    return;
  }

  char comando = cmd.charAt(0);
  switch (comando) {
    case 's': pruebaSensores(); break;
    case 'v': estadoPanel = "INIT"; pruebaServos(); publicarEstadoPanel(); break;
    case 'b': estadoPanel = "BUZZER"; sonarBuzzer(); break;
    case 'a': estadoPanel = "ATACAR"; avanzar(); publicarEstadoPanel(); delay(500); detenerRobot(); break;
    case 'd': estadoPanel = "DETENER"; detenerRobot(); publicarEstadoPanel(); break;
    default: break;
  }
}

void procesarComandoPanel(String cmd) {
  if (cmd == "CMD:TEST_SENSORES") {
    estadoPanel = "READ_LINE";
    pruebaSensores();
  } else if (cmd == "CMD:TEST_SERVOS") {
    estadoPanel = "INIT";
    pruebaServos();
    ultimoEstadoPanel = 0;
    publicarEstadoPanel();
  } else if (cmd == "CMD:TEST_BUZZER") {
    estadoPanel = "BUZZER";
    sonarBuzzer();
  } else if (cmd == "CMD:TEST_ULTRASONICO") {
    pruebaUltrasonico();
  } else if (cmd == "CMD:DEMO_BORDE") {
    estadoPanel = "EVITAR_BORDE";
    retroceder();
    ultimoEstadoPanel = 0;
    publicarEstadoPanel();
    sonarBuzzer(80);
    delay(250);
    detenerRobot();
    pausaPanelHasta = millis() + 700;
  } else if (cmd == "CMD:DEMO_ATAQUE") {
    estadoPanel = "ATACAR";
    avanzar();
    motorLeftPanel = "ATAQUE";
    motorRightPanel = "ATAQUE";
    ultimoEstadoPanel = 0;
    publicarEstadoPanel();
    delay(250);
    detenerRobot();
    pausaPanelHasta = millis() + 700;
  } else if (cmd == "CMD:DEMO_BUSCAR") {
    estadoPanel = "BUSCAR";
    girarDerecha();
    ultimoEstadoPanel = 0;
    publicarEstadoPanel();
    delay(250);
    detenerRobot();
    pausaPanelHasta = millis() + 700;
  } else if (cmd == "CMD:STOP") {
    estadoPanel = "DETENER";
    detenerRobot();
    pausaPanelHasta = millis() + 3000;
    ultimoEstadoPanel = 0;
    publicarEstadoPanel();
  } else {
    Serial.print("UNKNOWN_CMD:");
    Serial.println(cmd);
  }
}

void setServos(int leftUs, int rightUs) {
  pulsoServoLeft = constrain(leftUs, 1000, 2000);
  pulsoServoRight = constrain(rightUs, 1000, 2000);
}

void actualizarServos() {
  if (micros() - ultimoPulsoServo < SERVO_PERIOD_US) return;
  ultimoPulsoServo = micros();
  emitirPulsoServo(PIN_SERVO_LEFT, pulsoServoLeft);
  emitirPulsoServo(PIN_SERVO_RIGHT, pulsoServoRight);
}

void emitirPulsoServo(byte pin, int anchoUs) {
  digitalWrite(pin, HIGH);
  delayMicroseconds(anchoUs);
  digitalWrite(pin, LOW);
}

void publicarEstadoPanel() {
  unsigned long ahora = millis();
  if (ultimoEstadoPanel != 0 && ahora - ultimoEstadoPanel < PANEL_INTERVALO_MS) return;
  ultimoEstadoPanel = ahora;

  Serial.print("STATE:");
  Serial.println(estadoPanel);
  Serial.print("TCRT_LEFT:");
  Serial.println(ultimaLinea.left ? 1 : 0);
  Serial.print("TCRT_RIGHT:");
  Serial.println(ultimaLinea.right ? 1 : 0);
  Serial.print("TCRT_BACK:");
  Serial.println(ultimaLinea.back ? 1 : 0);
  Serial.print("DIST_CM:");
  Serial.println(ultimaDistanciaCm);
  Serial.print("OPONENTE:");
  Serial.println(ultimoOponenteDetectado ? 1 : 0);
  Serial.print("MOTOR_LEFT:");
  Serial.println(motorLeftPanel);
  Serial.print("MOTOR_RIGHT:");
  Serial.println(motorRightPanel);
  Serial.print("BUZZER:");
  Serial.println(buzzerPanel);
}

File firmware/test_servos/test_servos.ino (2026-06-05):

const byte PIN_SERVO_LEFT = 9;
const byte PIN_SERVO_RIGHT = 10;

const int SERVO_STOP_US = 1500;
const int SERVO_LEFT_FORWARD_US = 1700;
const int SERVO_LEFT_REVERSE_US = 1300;
const int SERVO_RIGHT_FORWARD_US = 1300;
const int SERVO_RIGHT_REVERSE_US = 1700;
const unsigned long SERVO_PERIOD_US = 20000UL;

void setup() {
  Serial.begin(9600);
  pinMode(PIN_SERVO_LEFT, OUTPUT);
  pinMode(PIN_SERVO_RIGHT, OUTPUT);
  detener();
  Serial.println("Prueba SG90 D9/D10 sin libreria Servo. Requiere rotacion continua para traccion.");
}

void loop() {
  Serial.println("Avanzar");
  moverDurante(SERVO_LEFT_FORWARD_US, SERVO_RIGHT_FORWARD_US, 800);
  detenerDurante(700);
  Serial.println("Retroceder");
  moverDurante(SERVO_LEFT_REVERSE_US, SERVO_RIGHT_REVERSE_US, 800);
  detenerDurante(1200);
}

void moverDurante(int pulsoLeft, int pulsoRight, unsigned long duracionMs) {
  unsigned long inicio = millis();
  while (millis() - inicio < duracionMs) {
    emitirPulsoServo(PIN_SERVO_LEFT, pulsoLeft);
    emitirPulsoServo(PIN_SERVO_RIGHT, pulsoRight);
    delayMicroseconds(SERVO_PERIOD_US - pulsoLeft - pulsoRight);
  }
}

void detenerDurante(unsigned long duracionMs) {
  moverDurante(SERVO_STOP_US, SERVO_STOP_US, duracionMs);
}

void detener() {
  digitalWrite(PIN_SERVO_LEFT, LOW);
  digitalWrite(PIN_SERVO_RIGHT, LOW);
}

void emitirPulsoServo(byte pin, int anchoUs) {
  digitalWrite(pin, HIGH);
  delayMicroseconds(anchoUs);
  digitalWrite(pin, LOW);
}

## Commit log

2026-06-05 Initial robot minisumo project structure
    [BOM_Robot_Minisumo.xlsx, robot_minisumo.kicad_sch]
2026-06-05 Align firmware and docs with tested TCRT pinout
    [robot_minisumo.kicad_sch]
2026-06-05 Finalize functional robot minisumo project
    [BOM_Robot_Minisumo.xlsx, Conexiones_Robot_Minisumo.xlsx, robot_minisumo.kicad_sch]
2026-06-05 Verify final functional firmware on Arduino Nano
